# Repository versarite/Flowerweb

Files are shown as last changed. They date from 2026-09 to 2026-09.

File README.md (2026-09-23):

# FlowerWeb
# Written with support from ChatGPT and Claude

A small web-controlled watering system for a Raspberry Pi. Open the web page from anywhere (for example over Tailscale), watch your plants on a live camera, water them with one click, or let a timer do it every 24, 48 or 72 hours.

The server is written in Free Pascal / Lazarus and runs as a systemd service. The camera stream is served by [MediaMTX](https://github.com/bluenviron/mediamtx).

## Features

- **Manual watering:** opens the valve for a set time (1–60 s by default)
- **Automatic watering:** every 24, 48 or 72 hours. The schedule survives restarts, and a watering missed while the Pi was off runs when it comes back.
- **Live camera:** a WebRTC stream from a USB webcam or the Raspberry Pi camera
- **Status:** shows the Pi's IP address, CPU temperature, next watering time and a countdown while watering
- **Remote reboot** from the web page
- **Safe valve handling:** the valve is closed at startup, at shutdown, when the service crashes and before a reboot, and the server enforces a maximum opening time

## Hardware

| Part | Notes |
|---|---|
| Raspberry Pi | Any model with GPIO. Uses `pinctrl` (Pi 5 / Bookworm) or `raspi-gpio` (older models) |
| Relay module | Signal on **GPIO 18** by default. Active-high and active-low boards are both supported (`ActiveLow` in the ini) |
| Water valve or pump | Switched by the relay. Use a separate power supply that suits the valve |
| Camera | USB webcam (`/dev/video0`) or Raspberry Pi camera module |

A ready-made **Raspberry Pi HAT** for all of this is in [`hardware/kicad`](hardware/kicad/README.md). It has a 5 V 6 A input jack, a 24 V step-up module, a TIP121 valve driver on GPIO 18, a 24 V valve jack and a status-LED header.

> ⚠️ The relay switches the valve's supply, not mains power. If your valve or pump runs on mains voltage, use a suitably rated relay and have the wiring checked by someone qualified.

The KiCAD hat board meant as a suggestion. No frills here, only GPIO18 is connected.   

## Project layout

```
flowerweb/
├── src/        Pascal source (Lazarus project flowerweb.lpi)
│   ├── flowerweb.lpr   program start, HTTP routes
│   ├── uconfig.pas     reads/writes config/flowerweb.ini
│   ├── uRelay.pas      valve control and watering timer
│   ├── uapi.pas        REST API
│   ├── uwebfiles.pas   serves the web page
│   ├── usysinfo.pas    CPU temperature and IP address
│   └── ulog.pas        logging
├── web/        index.html, app.js, style.css
├── config/     flowerweb.ini, mediamtx.yml (USB camera), mediamtx.yml_rpicam (Pi camera)
├── systemd/    flowerweb.service, mediamtx.service
├── scripts/    deploy.sh (build and install on the Pi), reset.sh (Wi-Fi watchdog)
├── hardware/   kicad/: FlowerWeb HAT schematic, board layout and BOM (see its README)
└── docs/       notes and command reference
```

On the Pi everything lives in `/home/flowerweb`, and the compiled program goes in `/home/flowerweb/bin`.

## Installation on the Raspberry Pi

1. **Install Lazarus** (for `lazbuild`) and create the folders:

   ```bash
   sudo apt install lazarus
   sudo mkdir -p /home/flowerweb/bin
   sudo chown -R pi:pi /home/flowerweb
   ```

2. **Install MediaMTX** for the camera. Download the ARM build from the [MediaMTX releases](https://github.com/bluenviron/mediamtx/releases) and put `mediamtx` in `/home/flowerweb/bin`. Copy the config that matches your camera:

   ```bash
   cp config/mediamtx.yml        /home/flowerweb/bin/mediamtx.yml   # USB webcam (needs ffmpeg)
   # or
   cp config/mediamtx.yml_rpicam /home/flowerweb/bin/mediamtx.yml   # Pi camera module
   ```

3. **Allow the service commands without a password** (`sudo visudo -f /etc/sudoers.d/flowerweb`):

   ```
   pi ALL=(root) NOPASSWD: /usr/sbin/reboot, /usr/bin/systemctl
   ```

4. **Install the services:**

   ```bash
   sudo cp /home/flowerweb/systemd/*.service /etc/systemd/system/
   sudo systemctl daemon-reload
   sudo systemctl enable --now mediamtx flowerweb
   ```

## Building and deploying

Development happens on a PC. `scripts/deploy.sh` copies the source to the Pi over SSH, compiles it there with `lazbuild`, installs it and restarts the service:

```bash
./scripts/deploy.sh
```

Set `PI_HOST` in the script to your Pi's address. Password-free SSH login is described in `docs/`.

### Testing without touching the live system

```bash
./scripts/deploy-test.sh          # copy, compile and start a test copy on port 8081
./scripts/deploy-test.sh log      # follow its log
./scripts/deploy-test.sh stop     # stop it
```

The test copy runs from `~/flowerweb-test` on the Pi in **simulation mode**. It only logs what it would do and never switches the relay or reboots the Pi. The live service, its folder and port 8080 are left alone. An orange banner on the page shows you're on the test copy. Simulation mode can also be switched on with `Simulate=1` in the ini or `--simulate` on the command line.

The Pi's `config/flowerweb.ini` is copied only the first time. After that, deploy leaves it alone so the settings you made from the web page are kept.

## Configuration

`config/flowerweb.ini`:

| Section | Key | Default | Meaning |
|---|---|---|---|
| Server | `Name` | FlowerWeb | Title shown on the web page |
| Server | `Port` | 8080 | HTTP port |
| Relay | `Pin` | 18 | GPIO pin for the relay |
| Relay | `ActiveLow` | 0 | `1` if the relay switches on when the pin is LOW |
| Relay | `PulseTimeMS` | 5000 | Valve opening time (set from the web page) |
| Relay | `MaxPulseTimeMS` | 60000 | Longest allowed opening time |
| Relay | `TimerInterval` | 0 | Hours between automatic waterings, `0` = off (set from the web page) |
| Relay | `NextWatering` | | Written by FlowerWeb. Next scheduled watering |
| Camera | `Name` / `Port` | cam / 8889 | MediaMTX path and WebRTC port |
| Logging | `Level` | INFO | `INFO` or `ERROR` |

Logs are written to `/home/flowerweb/logs/flowerweb.log`, which rolls over at 1 MB.

## Remote access

FlowerWeb has **no login**, so anyone who can reach port 8080 can water the plants and reboot the Pi. Keep it on your local network and reach it from outside through a VPN such as [Tailscale](https://tailscale.com). Don't forward the port to the internet.

Then open `http://<pi-address>:8080` in a browser.

## API

| Method | Path | Body | Description |
|---|---|---|---|
| GET | `/api/status` | | Status JSON (IP, temperature, timer, watering state, …) |
| POST | `/api/trigger` | `{"pulseTimeMS": 5000}` (optional) | Start watering. Returns `409` if already watering |
| POST | `/api/timer` | `{"timerInterval": 24}` | Set the automatic interval in hours (`0` = off) |
| POST | `/api/reboot` | | Close the valve and reboot the Pi |

Close the valve by hand at any time:

```bash
/home/flowerweb/bin/flowerweb --relay-off
```

## License

FlowerWeb is released under the [PolyForm Noncommercial License 1.0.0](LICENSE.md). You're free to use, study, change and share it for any **non-commercial** purpose: personal projects, hobby use, education, research, and charitable or public organisations. Commercial use is not permitted without the author's permission.

Copyright (c) 2026 DL1BWA

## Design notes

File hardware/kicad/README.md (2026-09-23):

# FlowerWeb HAT (KiCad)

A Raspberry Pi HAT (65 × 56.5 mm, 2 layers) that powers the Pi from a 5 V barrel jack and switches a 24 V valve from GPIO18.

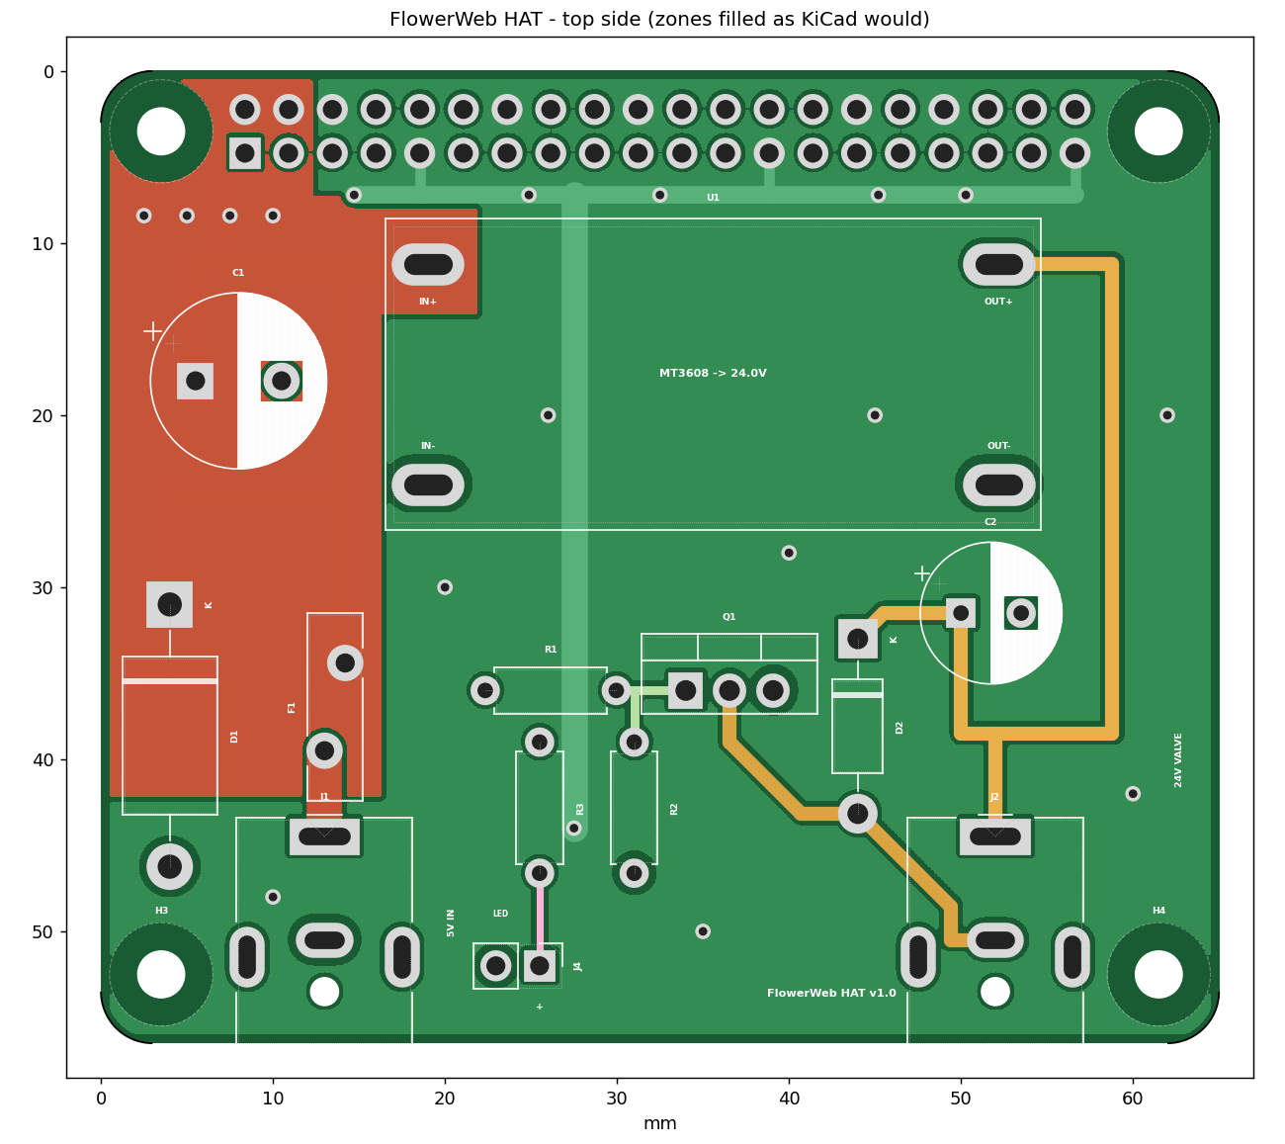
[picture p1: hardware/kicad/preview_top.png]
Top side


## Files

| File | What it is |
|---|---|
| `flowerweb_hat.kicad_pro` | KiCad project. Open this one |
| `flowerweb_hat.kicad_sch` | Schematic (also as `schematic.pdf`) |
| `flowerweb_hat.kicad_pcb` | Board layout |
| `flowerweb.kicad_sym`, `flowerweb.pretty/` | Project symbol and footprint library (MT3608 module footprint) |
| `BOM.csv` | Parts list |
| `preview_*.png` | Rendered previews |

Written in KiCad 7 format, so it opens in KiCad 7, 8 and 9. All other footprints come from the standard KiCad libraries.

## Circuit

- **5 V input (J1):** PJ-063AH jack (5.5 × 2.1 mm, rated 8 A) → F1 6 A resettable fuse → +5V. D1 (1.5KE6V8A TVS) clamps overvoltage and conducts if the plug is reversed, which trips F1. C1 470 µF is bulk capacitance.
- **Raspberry Pi (J3):** 2 × 20 socket on the **bottom** side. +5V goes to pins 2 and 4 (the Pi is back-powered through the header), GND to all eight ground pins.
- **24 V (U1):** MT3608 step-up module, 5 V → 24 V, with C2 100 µF / 35 V on the output.
- **Valve driver:** GPIO18 (pin 12) → R1 1 kΩ → TIP121 base. R2 10 kΩ pulls the base low so the valve stays shut while the Pi boots. The TIP121 switches the low side of the valve, and D2 (1N4007) absorbs the coil's turn-off spike.
- **Valve jack (J2):** PJ-063AH. Centre pin = **+24 V**, sleeve = **switched side**. The sleeve is *not* ground, so don't connect it to anything else.
- **Status LED (J4):** 3.3 V (pin 17) → R3 220 Ω → header pin 1 (LED +). Pin 2 = LED −. That's about 6 mA for a red or green LED. Use a lower value (e.g. 68 Ω) for blue or white.

## Before ordering

1. Open `flowerweb_hat.kicad_pro` in KiCad.
2. In the PCB editor press **B** (Fill all zones). The copper pours are saved unfilled. Every connection, GND and 5V included, is also made by traces, so there are no ratsnest lines even before filling. The pours add copper area for the 5 A current, so always fill them before ordering.
3. Run **Inspect → Design Rules Checker** and, in the schematic, **Inspect → Electrical Rules Checker**. The board was checked with independent clearance, pour and connectivity checks while it was being made, but it has not yet been opened in KiCad itself. Run both checks once before ordering.
4. Optional: **Tools → Update Footprints from Library** adds the 3D models for the 3D viewer. Afterwards, check that J3's pin 1 is still next to mounting hole H1.
5. Plot Gerbers and drill files (**File → Fabrication Outputs**). The board uses standard rules (0.2 mm clearance, 0.3 mm tracks, 0.4 mm vias) that every PCB fab supports. The MT3608 pads have **slotted holes**, which most fabs (JLCPCB, PCBWay, Aisler) make at no extra cost.

## Assembly notes

- **Set the MT3608 to 24.0 V before soldering it in.** Feed it 5 V, turn the trimmer and measure. The TIP121 drops about 1 V, so the valve sees roughly 23 V. Set 25 V if your valve needs the full 24.
- MT3608 modules differ slightly between sellers. Line up the **IN+ / IN− / OUT+ / OUT−** marks on the PCB with the ones on the module. The slotted pads allow about ±1 mm. Solder the module on with short wire legs (cut resistor leads work).
- Solder the 2 × 20 socket on the **bottom** side. Mount the HAT with M2.5 standoffs. The usual height is 11–12 mm, but measure yours with the socket plugged in.
- Raspberry Pi 5: add `usb_max_current_enable=1` to `/boot/firmware/config.txt`. Otherwise the Pi 5 limits USB current when it's powered through the GPIO header.
- The TIP121 needs no heatsink at 150 mA (about 0.15 W).
- No ID EEPROM and no camera/display cable slot are included.

## License

PolyForm Noncommercial 1.0.0. See `LICENSE.md` in the project root.
Copyright DL1BWA 2026

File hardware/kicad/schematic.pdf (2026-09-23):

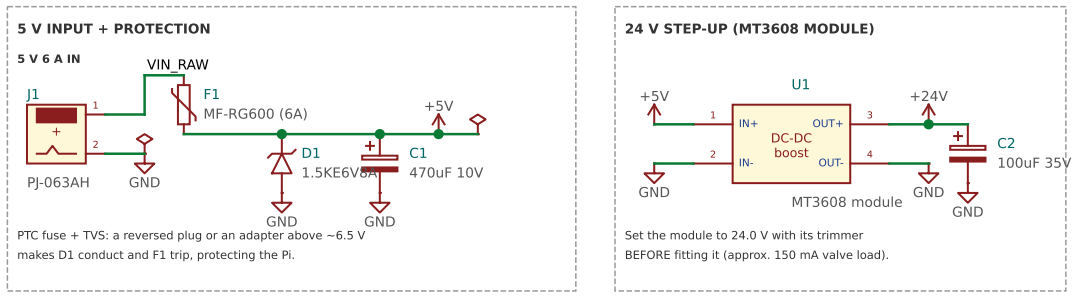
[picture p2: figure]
GND; DC-DC boost; OUT+; OUT-; MT3608 module; 5 V INPUT + PROTECTION; 24 V STEP-UP (MT3608 MODULE); VIN_RAW

PTC fuse + TVS: a reversed plug or an adapter above ~6.5 V makes D1 conduct and F1 trip, protecting the Pi.

Set the module to 24.0 V with its trimmer BEFORE fitting it (approx. 150 mA valve load).

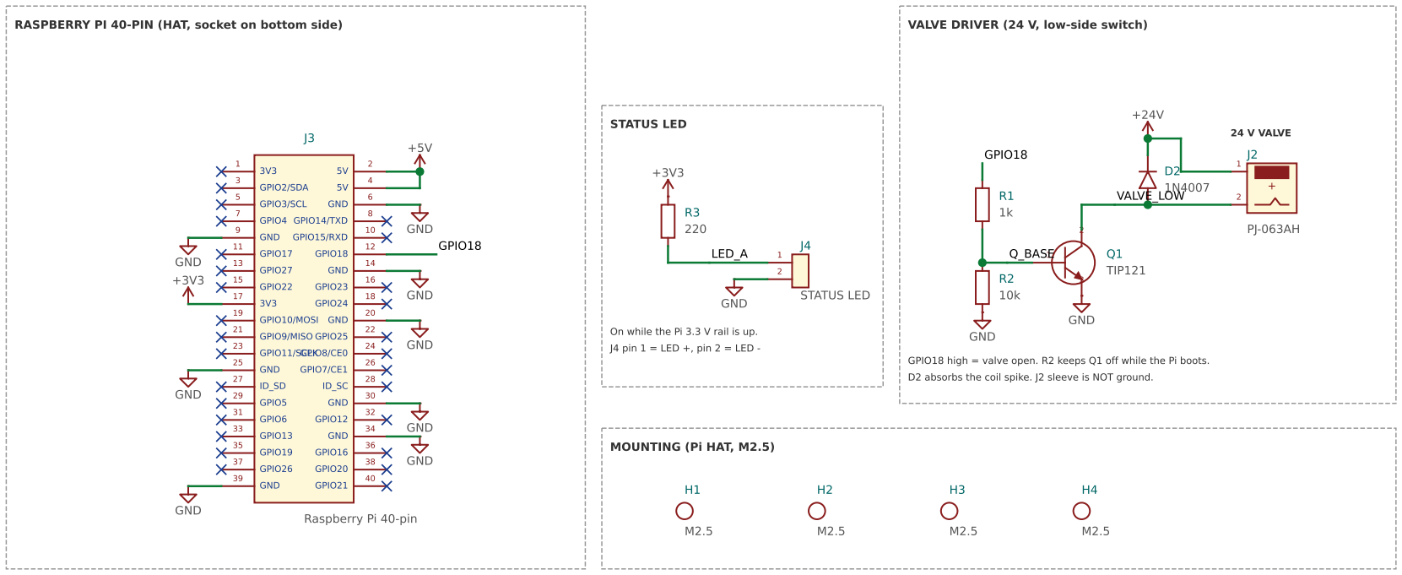
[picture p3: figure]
GPIO2/SDA; GPIO3/SCL; GND; GPIO4; GPIO14/TXD; GPIO15/RXD; GPIO17; GPIO18; GPIO27; GPIO22; GPIO23; GPIO24; GPIO10/MOSI; GPIO9/MISO; GPIO25; GPIO11/SCLK; GPIO8/CE0; GPIO7/CE1; GPIO5; GPIO6; GPIO12; GPIO13; GPIO19; GPIO16; GPIO26; GPIO20; GPIO21; Raspberry Pi 40-pin; TIP121; STATUS LED; 24 V VALVE; On while the Pi 3.3 V rail is up.; J4 pin 1 = LED +, pin 2 = LED -; MOUNTING (Pi HAT, M2.5); Q_BASE; VALVE_LOW; LED_A

RASPBERRY PI 40-PIN (HAT, socket on bottom side) | VALVE DRIVER (24 V, low-side switch)

GPIO18 high = valve open. R2 keeps Q1 off while the Pi boots. D2 absorbs the coil spike. J2 sleeve is NOT ground.

NOTES

1. Board outline follows the Raspberry Pi HAT size (65 x 56.5 mm, M2.5 holes). No ID EEPROM is fitted.
2. The Pi is powered through GPIO pins 2/4 (back-powering). On a Pi 5 add usb_max_current_enable=1 to config.txt.
3. MT3608 modules differ slightly between sellers: match the IN+/IN-/OUT+/OUT- labels on the PCB to the module.
4. PJ-063AH jacks fit 5.5 x 2.1 mm plugs and are rated 8 A / 24 V.

## FlowerWeb HAT - Raspberry Pi watering controller rev 1.0 2026-09-23

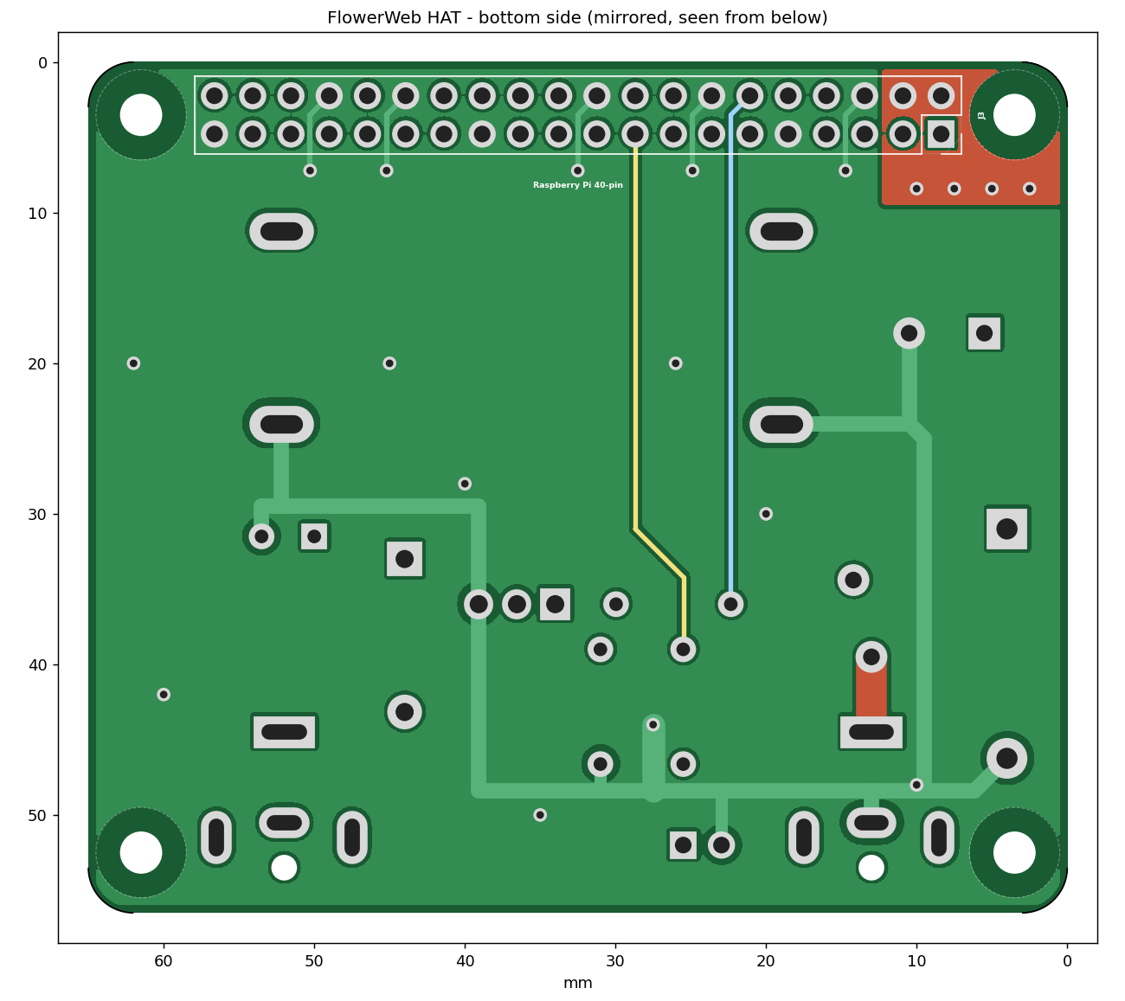
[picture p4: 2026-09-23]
hardware/kicad/preview_bottom.png

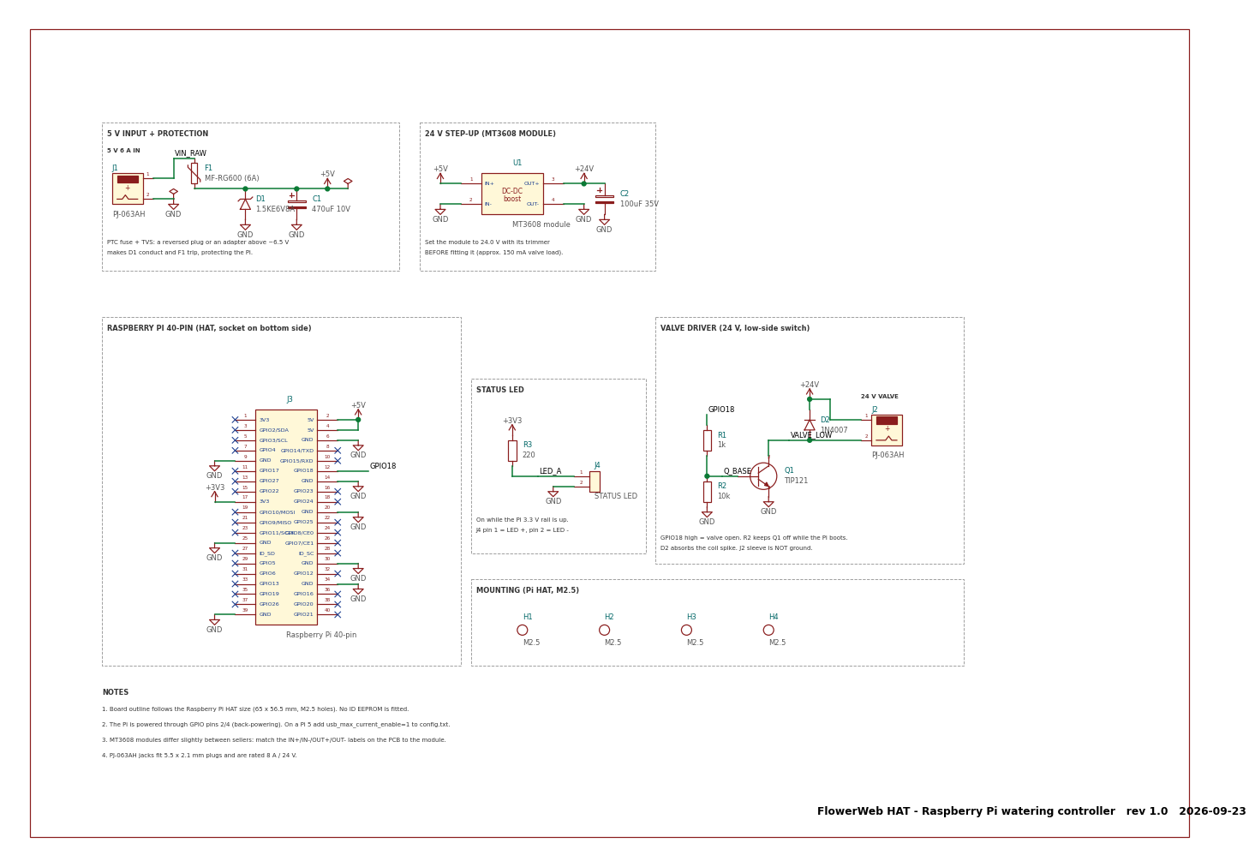
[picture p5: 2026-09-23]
hardware/kicad/preview_schematic.png

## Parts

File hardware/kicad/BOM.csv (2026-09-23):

Ref | Qty | Value | Part / MPN | Description | Footprint
C1 | 1 | 470uF 10V |  | Electrolytic, 10 mm dia, 5 mm pitch, >=10 V | Capacitor_THT:CP_Radial_D10.0mm_P5.00mm
C2 | 1 | 100uF 35V |  | Electrolytic, 8 mm dia, 3.5 mm pitch, >=35 V | Capacitor_THT:CP_Radial_D8.0mm_P3.50mm
D1 | 1 | 1.5KE6V8A | 1.5KE6V8A | TVS 1500 W, 5.8 V standoff, unidirectional | Diode_THT:D_DO-201AE_P15.24mm_Horizontal
D2 | 1 | 1N4007 | 1N4007 | Flyback diode across the valve coil | Diode_THT:D_DO-41_SOD81_P10.16mm_Horizontal
F1 | 1 | MF-RG600 (6A) | Bourns MF-RG600 | PTC resettable fuse, Ihold 6 A, 16 V | Fuse:Fuse_Bourns_MF-RG600
H1 H2 H3 H4 | 4 | M2.5 |  | Pi mounting hole | MountingHole:MountingHole_2.7mm_M2.5
J1 | 1 | PJ-063AH | CUI/Same Sky PJ-063AH | 5 V 6 A input jack, 5.5x2.1 mm, rated 8 A | Connector_BarrelJack:BarrelJack_CUI_PJ-063AH_Horizontal
J2 | 1 | PJ-063AH | CUI/Same Sky PJ-063AH | Centre = +24 V, sleeve = switched (NOT ground) | Connector_BarrelJack:BarrelJack_CUI_PJ-063AH_Horizontal
J3 | 1 | Raspberry Pi 40-pin | 2x20 female header 2.54 mm (8.5 mm) | Mounted on the bottom side | Connector_PinSocket_2.54mm:PinSocket_2x20_P2.54mm_Vertical
J4 | 1 | STATUS LED | 1x2 pin header 2.54 mm | Pin 1 = LED anode (+), pin 2 = cathode | Connector_PinHeader_2.54mm:PinHeader_1x02_P2.54mm_Vertical
Q1 | 1 | TIP121 | TIP121 | NPN Darlington 80 V 5 A, TO-220 | Package_TO_SOT_THT:TO-220-3_Vertical
R1 | 1 | 1k |  | 0.25 W | Resistor_THT:R_Axial_DIN0207_L6.3mm_D2.5mm_P7.62mm_Horizontal
R2 | 1 | 10k |  | 0.25 W, keeps the valve off while the Pi boots | Resistor_THT:R_Axial_DIN0207_L6.3mm_D2.5mm_P7.62mm_Horizontal
R3 | 1 | 220 |  | 0.25 W, LED current approx. 6 mA | Resistor_THT:R_Axial_DIN0207_L6.3mm_D2.5mm_P7.62mm_Horizontal
U1 | 1 | MT3608 module | MT3608 DC-DC step-up module | 2 A boost module, 37x17 mm, adjust to 24.0 V | flowerweb:MT3608_Module

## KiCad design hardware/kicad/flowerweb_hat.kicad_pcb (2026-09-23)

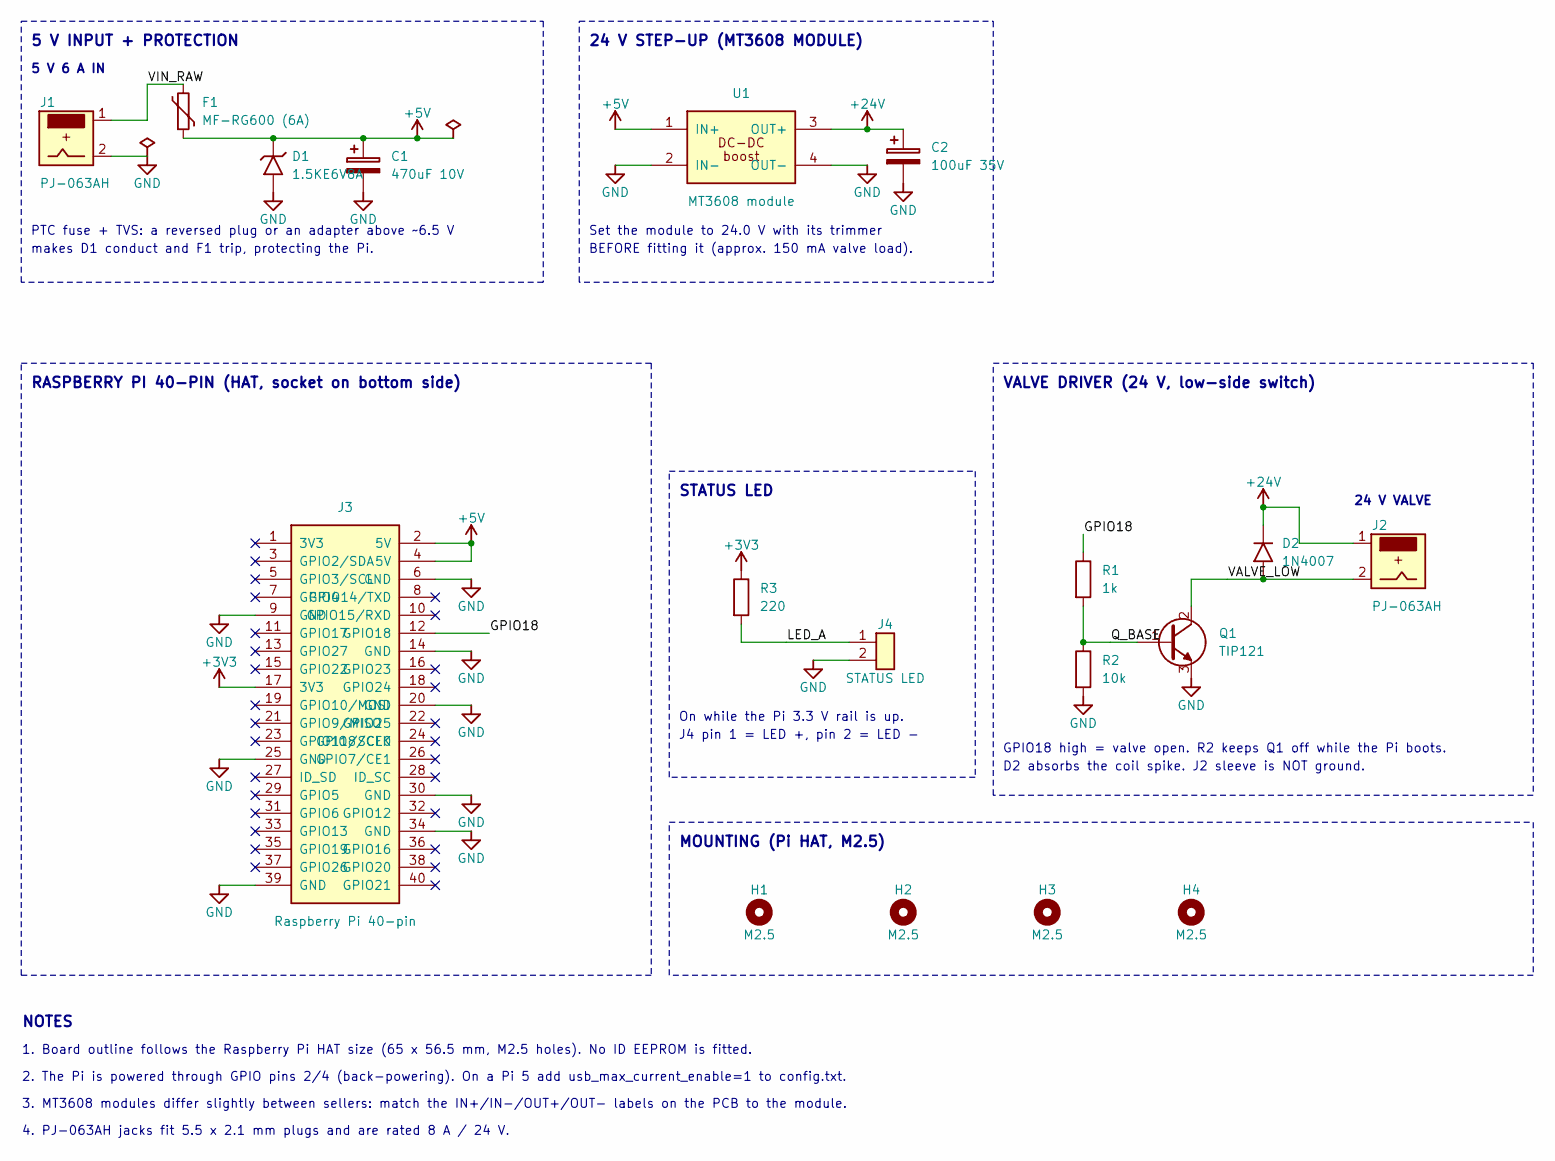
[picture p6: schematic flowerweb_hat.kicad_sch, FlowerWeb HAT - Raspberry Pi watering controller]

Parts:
C1: 470uF 10V; CP_Radial_D10.0mm_P5.00mm
C2: 100uF 35V; CP_Radial_D8.0mm_P3.50mm
D1: 1.5KE6V8A; D_DO-201AE_P15.24mm_Horizontal; MPN 1.5KE6V8A
D2: 1N4007; D_DO-41_SOD81_P10.16mm_Horizontal; MPN 1N4007
F1: MF-RG600 (6A); Fuse_Bourns_MF-RG600; MPN Bourns MF-RG600
H1, H2, H3, H4: M2.5; MountingHole_2.7mm_M2.5
J1, J2: PJ-063AH; BarrelJack_CUI_PJ-063AH_Horizontal; MPN CUI/Same Sky PJ-063AH
J3: Raspberry Pi 40-pin; PinSocket_2x20_P2.54mm_Vertical; MPN 2x20 female header 2.54 mm (8.5 mm)
J4: STATUS LED; PinHeader_1x02_P2.54mm_Vertical; MPN 1x2 pin header 2.54 mm
Q1: TIP121; TO-220-3_Vertical; MPN TIP121
R1: 1k; R_Axial_DIN0207_L6.3mm_D2.5mm_P7.62mm_Horizontal
R2: 10k; R_Axial_DIN0207_L6.3mm_D2.5mm_P7.62mm_Horizontal
R3: 220; R_Axial_DIN0207_L6.3mm_D2.5mm_P7.62mm_Horizontal
U1: MT3608 module; MT3608_Module; MPN MT3608 DC-DC step-up module

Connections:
+3V3: J3.17 (3V3), R3.1
+5V: C1.1, D1.1 (K), F1.2, J3.2 (5V), J3.4 (5V), U1.1 (IN+)
+24V: C2.1, D2.1 (K), J2.1, U1.3 (OUT+)
/GPIO18: J3.12 (GPIO18), R1.1
/LED_A: J4.1, R3.2
/Q_BASE: Q1.1 (B), R1.2, R2.1
/VALVE_LOW: D2.2 (A), J2.2, Q1.2 (C)
/VIN_RAW: F1.1, J1.1
GND: C1.2, C2.2, D1.2 (A), J1.2, J3.6 (GND), J3.9 (GND), J3.14 (GND), J3.20 (GND), J3.25 (GND), J3.30 (GND), J3.34 (GND), J3.39 (GND), J4.2, Q1.3 (E), R2.2, U1.2 (IN-), U1.4 (OUT-)

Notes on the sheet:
5 V INPUT + PROTECTION
5 V 6 A IN
PTC fuse + TVS: a reversed plug or an adapter above ~6.5 V
makes D1 conduct and F1 trip, protecting the Pi.
24 V STEP-UP (MT3608 MODULE)
Set the module to 24.0 V with its trimmer
BEFORE fitting it (approx. 150 mA valve load).
RASPBERRY PI 40-PIN (HAT, socket on bottom side)
VALVE DRIVER (24 V, low-side switch)
24 V VALVE
GPIO18 high = valve open. R2 keeps Q1 off while the Pi boots.
D2 absorbs the coil spike. J2 sleeve is NOT ground.
STATUS LED
On while the Pi 3.3 V rail is up.
J4 pin 1 = LED +, pin 2 = LED -
MOUNTING (Pi HAT, M2.5)
NOTES
1. Board outline follows the Raspberry Pi HAT size (65 x 56.5 mm, M2.5 holes). No ID EEPROM is fitted.
2. The Pi is powered through GPIO pins 2/4 (back-powering). On a Pi 5 add usb_max_current_enable=1 to config.txt.
3. MT3608 modules differ slightly between sellers: match the IN+/IN-/OUT+/OUT- labels on the PCB to the module.
4. PJ-063AH jacks fit 5.5 x 2.1 mm plugs and are rated 8 A / 24 V.

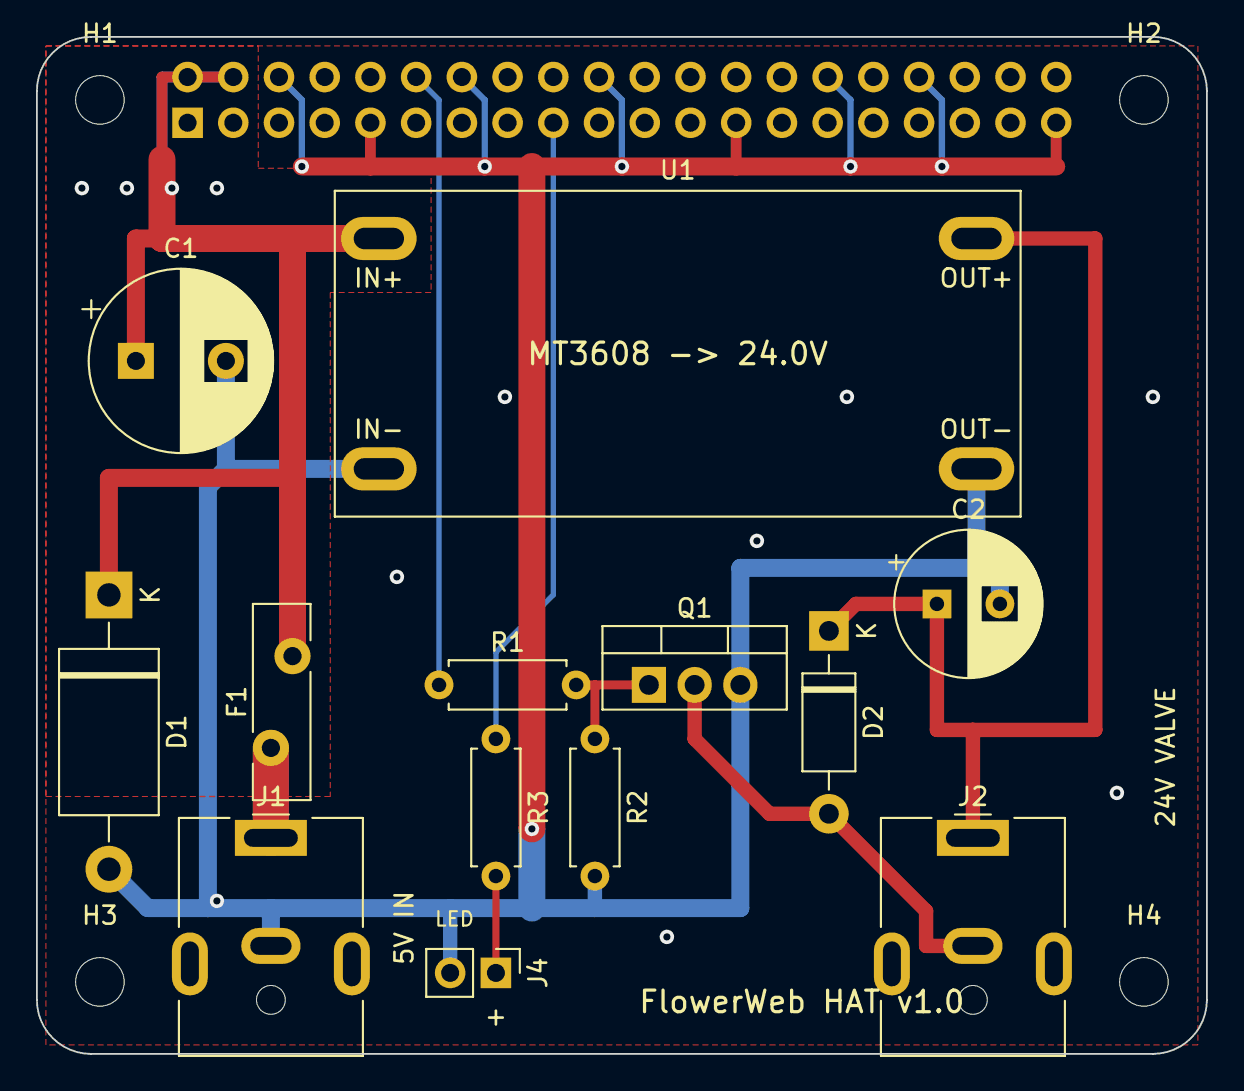
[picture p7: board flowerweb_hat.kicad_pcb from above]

Board: 2 copper layers, 65.0 x 56.5 mm, 18 parts (1 on the bottom side), 9 nets.

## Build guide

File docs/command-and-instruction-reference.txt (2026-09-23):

============================================================
FLOWERWEB DEVELOPMENT COMMAND REFERENCE
============================================================

SSH
------------------------------------------------------------

ssh pi@192.168.43.218
Connect to the Raspberry Pi using the current user's SSH key.

ssh -v pi@192.168.43.218
Verbose SSH connection. Useful for diagnosing authentication problems.

Important:
Do NOT use "sudo ssh".
Doing so causes SSH to use /root/.ssh instead of ~/.ssh.

------------------------------------------------------------

DEPLOYMENT
------------------------------------------------------------

./scripts/deploy.sh
Synchronize the project, compile remotely, install the executable and restart the service.

------------------------------------------------------------

RSYNC
------------------------------------------------------------

rsync -av src/    pi@192.168.43.218:/home/flowerweb/src/
Synchronize Pascal source files.

rsync -av web/    pi@192.168.43.218:/home/flowerweb/web/
Synchronize HTML, CSS and JavaScript.

rsync -av config/ pi@192.168.43.218:/home/flowerweb/config/
Synchronize configuration files.

------------------------------------------------------------

BUILD
------------------------------------------------------------

cd /home/flowerweb/src

rm -f flowerweb
Delete the previous executable before compiling.

lazbuild flowerweb.lpi
Compile the Lazarus project.

cp -f flowerweb ../bin/
Install the new executable.

------------------------------------------------------------

SYSTEMD
------------------------------------------------------------

sudo systemctl restart flowerweb
Restart the FlowerWeb service.

sudo systemctl status flowerweb --no-pager
Display the service status without invoking the pager.

systemctl cat flowerweb
Display the installed service file.

systemctl cat mediamtx
Display the MediaMTX service file.

sudo systemctl daemon-reload
Reload all modified service files.

------------------------------------------------------------

SUDO CONFIGURATION
------------------------------------------------------------

sudo -l
Display all commands the current user may execute via sudo.

sudo visudo -f /etc/sudoers.d/flowerweb
Create or edit the FlowerWeb sudo policy.

------------------------------------------------------------

SERVICE FILES
------------------------------------------------------------

FlowerWeb:
/etc/systemd/system/flowerweb.service

MediaMTX:
/etc/systemd/system/mediamtx.service

Project archive:
~/Projects/flowerweb/services/

------------------------------------------------------------

MEDIA MTX
------------------------------------------------------------

sudo nano /etc/systemd/system/mediamtx.service

Recommended addition:

TimeoutStopSec=10

After editing:

sudo systemctl daemon-reload
sudo systemctl restart mediamtx

------------------------------------------------------------

SYSTEM INFORMATION
------------------------------------------------------------

which systemctl
Display the absolute path of the systemctl executable.

------------------------------------------------------------

LOGS
------------------------------------------------------------

journalctl -b -1 -e
Display the end of the previous boot log.
Useful for diagnosing slow shutdowns and reboot delays.

journalctl -b -1 | grep -i "stop job"
Search the previous shutdown log for services delaying system shutdown.

------------------------------------------------------------

PROJECT STRUCTURE
------------------------------------------------------------

flowerweb/
│
├── src/
├── web/
├── config/
├── services/
│   ├── flowerweb.service
│   └── mediamtx.service
├── scripts/
└── bin/            (Raspberry Pi only)

------------------------------------------------------------

PROJECT UNITS
------------------------------------------------------------

flowerweb.lpr    Application startup

uconfig          Configuration

uwebfiles        HTML/CSS/JS delivery

uapi             REST API

usysinfo         CPU temperature and IP address

ulog             Logging

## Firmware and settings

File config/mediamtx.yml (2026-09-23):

###############################################
# Global settings

# Settings in this section are applied anywhere.

###############################################
# Global settings -> General

# Verbosity of the program; available values are "error", "warn", "info", "debug".
logLevel: info
# Destinations of log messages; available values are "stdout", "file" and "syslog".
logDestinations: [stdout]
# When destination is "stdout" or "file", emit logs in structured format (JSONL).
logStructured: false
# When "file" is in logDestinations, this is the file which will receive logs.
logFile: mediamtx.log
# When "syslog" is in logDestinations, use prefix for logs.
sysLogPrefix: mediamtx
# Dump packets to disk. This is useful for debugging.
dumpPackets: false

# Timeout of read operations.
readTimeout: 10s
# Timeout of write operations.
writeTimeout: 10s
# Size of the queue of outgoing packets.
# A higher value allows to increase throughput, a lower value allows to save RAM.
writeQueueSize: 512
# Maximum size of outgoing UDP payloads.
# It defaults to the maximum packet size on ethernet (1500) minus IPv6 and UDP headers (48).
# This can be decreased to avoid fragmentation on networks with a low MTU.
udpMaxPayloadSize: 1452
# Size of the read buffer of every UDP socket.
# This can be increased to decrease packet losses.
# It defaults to the default value of the operating system.
udpReadBufferSize: 0

# Command to run when a client connects to the server.
# This is terminated with SIGINT when a client disconnects from the server.
# The following environment variables are available:
# * MTX_CONN_TYPE: connection type
# * MTX_CONN_ID: connection ID
# * RTSP_PORT: RTSP server port
runOnConnect:
# Restart the command if it exits.
runOnConnectRestart: false
# Command to run when a client disconnects from the server.
# Environment variables are the same as runOnConnect.
runOnDisconnect:

###############################################
# Global settings -> Authentication

# Authentication method. Available values:
# * Internal database: credentials are stored in the configuration file
# * External HTTP server: an external HTTP URL is contacted for each authentication request
# * External JWT provider: credentials are signed tokens released by an external identity server
authMethod: internal

# Internal authentication.
# Enabled users.
authInternalUsers:
  # Default unprivileged user.
  # Username. 'any' means any user, including anonymous ones.
  - user: any
    # Password. Not used in case of 'any' user.
    pass:
    # IPs or networks allowed to use this user. An empty list means any IP.
    ips: []
    # Permissions.
    permissions:
      # Available actions are: publish, read, playback, api, metrics, pprof.
      - action: publish
        # Paths can be set to further restrict access to a specific path.
        # An empty path means any path.
        # Regular expressions can be used by using a tilde as prefix.
        path:
      - action: read
        path:
      - action: playback
        path:

    # Default administrator.
    # This allows to use API, metrics and PPROF without authentication,
    # if the IP is localhost.
  - user: any
    pass:
    ips: ["127.0.0.1", "::1"]
    permissions:
      - action: api
      - action: metrics
      - action: pprof

# HTTP-based authentication.
# URL called to perform authentication. Every time a user wants
# to authenticate, the server calls this URL with the POST method
# and a payload described in the documentation.
# If the response code is 20x, authentication is accepted, otherwise
# it is discarded.
authHTTPAddress:
# If the HTTP authentication URL has a self-signed or invalid certificate,
# you can provide the fingerprint of the certificate in order to
# validate it anyway. It can be obtained by running:
# openssl s_client -connect auth_http_domain:443 </dev/null 2>/dev/null | sed -n '/BEGIN/,/END/p' > server.crt
# openssl x509 -in server.crt -noout -fingerprint -sha256 | cut -d "=" -f2 | tr -d ':'
authHTTPFingerprint:
# Actions to exclude from HTTP-based authentication.
# Format is the same as the one of user permissions.
authHTTPExclude:
  - action: api
  - action: metrics
  - action: pprof
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

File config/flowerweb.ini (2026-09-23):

[Paths]
; Relative paths are relative to the install directory (/home/flowerweb)
WebRoot=web
LogRoot=logs
ConfigRoot=config

[Server]
Name=Green House M.D.
Port=8080

[Relay]
Pin=18
; 0 = relay switches ON when the pin is HIGH, 1 = ON when LOW
ActiveLow=0
; 1 = test mode: never touch GPIO or reboot, only log what would happen
Simulate=0
; Valve opening time. Changed from the web page; always kept between 1000 and MaxPulseTimeMS
PulseTimeMS=5000
MaxPulseTimeMS=60000
; Automatic watering interval in hours, 0 = disabled. Changed from the web page.
TimerInterval=0
; Written by FlowerWeb so the schedule survives restarts
NextWatering=

[Camera]
Name=cam
Port=8889

[Logging]
; INFO or ERROR
Level=INFO
File=flowerweb.log

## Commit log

2026-09-23 bug fixes
    [flowerweb_hat.kicad_pcb]
2026-09-23 bug fixes and sim mode added
    [flowerweb.ini]
